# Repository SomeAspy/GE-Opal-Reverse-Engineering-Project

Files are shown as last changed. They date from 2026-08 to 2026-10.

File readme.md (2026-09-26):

# GE-Opal-Reverse-Engineering-Project

This repository documents all my attempts to make the GE Opal 2 not kill itself
(More specifically, the *GE Profile:tm: Opal:tm: 2.0 Ultra Nugget Ice Maker )

Important context to a lot of frustration here: This is a $500 dollar ice machine. It has a lifespan of 6 months to 1 year

## Consider sponsoring

I have quite literally dumped hundreds of dollars into this project.
Some of the costs are prototyping modules, connectors, electronics components, and OEM parts for the machine.

**Money spent on this project so far: $768.73**

_this does not factor in my time spent on the project_

(500 dollar ice machine by the way)

## Directory

- [`reverse-engineering-efforts/`](./reverse-engineering-efforts) - Generally contains specifics about the hardware of the Opal 2
  - [`i2c.md`](./reverse-engineering-efforts/i2c.md) - Details of the I2C implementation in the original machine
  - [`pipes.d2`](./reverse-engineering-efforts/pipes.d2) - D2 file for generating `pipes.svg`
  - [`pipes.svg`](./reverse-engineering-efforts/pipes.svg) - How the Opal 2 is plumbed
- [`physical-repairs/`](./physical-repairs) - Details of specific repair efforts
  - [`gearboxRepair.md`](physical-repairs/gearboxRepair.md) - Details about the gearbox and the procedures and parts to fix it
  - [`squeakFromShaft.md`](physical-repairs/squeakFromShaft.md) - Details about a repair attempting to stop the squeaking shaft
- [`hardware/`](./hardware) - PCB related stuff
  - [`RoughSketch-ArduinoNanoESP32`](./hardware/RoughSketch-ArduinoNanoESP32) - Details the rough prototype build with modular components before the PCB fabrication
    - [`prototype-parts.md`](./hardware/RoughSketch-ArduinoNanoESP32/prototype-parts.md) - A list of the exact modules I used for prototyping
    - [`Schematic.pdf`](./hardware/RoughSketch-ArduinoNanoESP32/Schematic.pdf) - A human readable version of the schematic, made by printing to PDF from KiCAD
- [`attribution.md`](./attribution.md) - Links and references used for files
- [`todo.md`](./todo.md) - List of further research needed

## To Do

(in no specific order)

- [ ] Finish connectors.md with colors and diagrams
- [ ] Design PCB
- [ ] Reverse engineer I2C bus of other front panel [(Need parts)](./todo.md)
- [ ] Design full independent schematic
- [ ] Reverse engineer GE implementation of the RGB light [(Need parts)](./todo.md)

## Default button mappings

A few new button actions are defined, and a few changed from the original machine behavior

- **Power**: Toggles Power
  - **When held**: Triggers a hard reset of the Arduino. _I hope you know what you're doing_
- **Light**: Toggles Light
- **Clean**: Toggles cleaning mode. In my implementation, there is no timer or anything. It simply forces the pump to run until it is pressed again.

## The Prototype

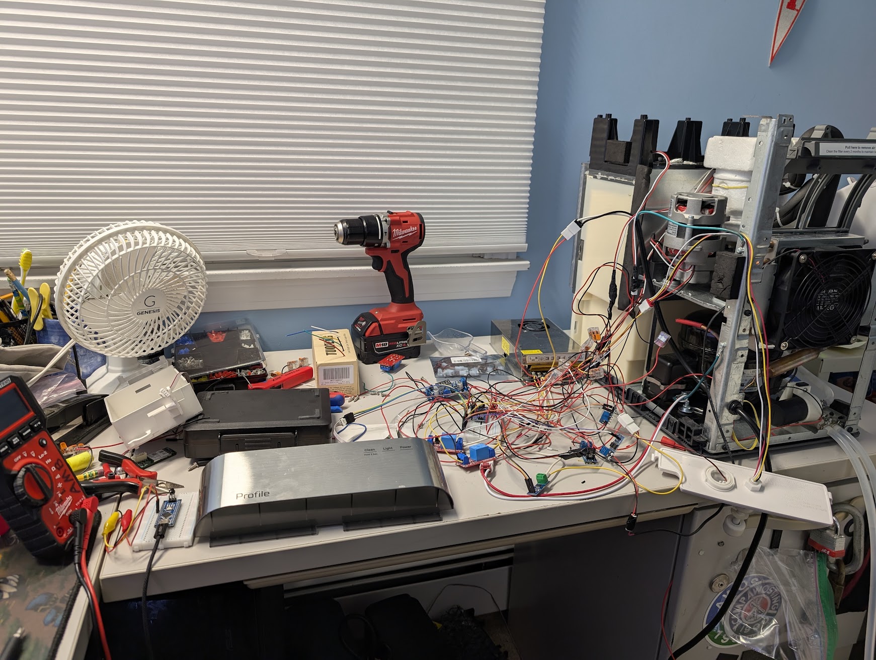
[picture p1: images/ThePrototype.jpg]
Mess of wires and stuff coming from the ice machine


> [!WARNING]  
> Schematics and code are not final!

### LLM Policy and usage in this project:

I hate LLMs, and "AI" crap. Therefore, I decided to very clearly define how they were used in this project.

- I did **NOT** copy-paste code or otherwise use LLM generated material in this project's code.
- An LLM was used to help me understand how to use KiCAD because I have never used it before.
- An LLM was used to sanity check ([rubber ducky](https://en.wikipedia.org/wiki/Rubber_duck_debugging)) to avoid killing the machine.
- An LLM was used to help me understand the basics of I2C and reverse engineer the communication the Opal uses.
  - **I** implemented the I2C communications in the firmware.

Do **NOT** submit LLM generated issues, PRs, or use this repo in training data.

You **MAY** submit an **issue** that you made with the assistance of an LLM, but you must **paraphrase and understand** the content in your own words.

### My blog post on this

[A Scathing Review of the GE Opal 2 Nugget Ice Maker](https://blog.aspy.dev/a-scathing-review-of-the-ge-opal-2-nugget-ice-maker/)

# Background

I've tried putting lubrication on the auger ([`squeakFromShaft.md`](./physical-repairs/squeakFromShaft.md)) but it did not resolve the squeaking issue
I've decided I am going to replace the PCB with an arduino to implement a proper defrost cycle.

## Notice

As I was writing this, Reddit decided to delete the 2 year old post I was using as a reference.
Some of the more important images are available in [`images`](./images).

<https://web.archive.org/web/20250804095737/https://www.reddit.com/r/IceChewersAnonymous/comments/1hxlbkg/fixing_the_opal_20/>

## The Problem

The GE Opal ice maker has well-known issues where it will start to fail after about a year of use, and in some cases, prior.
The machine is incredibly high maintenance, [with GE recommending running bleach through the machine](https://products.geappliances.com/appliance/gea-support-search-content?contentId=000060634) ([archive.org capture](https://web.archive.org/web/20260716162758/https://products.geappliances.com/appliance/gea-support-search-content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))

There is even (as of writing) [an ongoing class action](https://classlawdc.com/2026/01/21/ge-profile-opalnugget-ice-maker-series-1-0-and-2-0-defective-product-investigation/)

These machines do not fail gracefully, often making screeching and whining noises due to the internal parts getting frozen and locked up. This commonly involves the destruction of the gearbox, auger, and/or bearings.

Browsing Reddit reveals many owners have constant issues with these machines, with one redditor even claiming to go through 4 machines in 2 years. Despite its flaws, this machine is well liked by r/IceChewersAnonymous, though they also agree that it has significant longevity issues. [A quick search shows the love/hate the community has for it.](https://www.reddit.com/r/IceChewersAnonymous/search/?q=opal+2)

More importantly, several members of the community have taken attempts to repair the machine pretty far.

- https://www.reddit.com/r/IceChewersAnonymous/comments/1ophadu/opal_20_repair_update/
- https://www.reddit.com/r/IceChewersAnonymous/comments/1hxlbkg/fixing_the_opal_20/
- https://www.reddit.com/r/IceChewersAnonymous/comments/159ts6e/ge_opal_20_add_water_fix/

# Piping

Piping

# Nominal voltages recorded from the opal 2 ice maker during operation

_I am aware that JST XHB is not a real standard. However, this is the bastardized cloned modification China has made. it is a JST XH connector with a locking tab. You will not find them on Amazon, or Digikey. I found mine [on Aliexpress](https://www.aliexpress.us/item/3256812673164043.html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)._

_Same applies to JST HY. With some help from ~~the Arduino Community~~[^1] a specific member of the Arduino community and JLCPCB, I was able to find what appears to be a matching connector.
~~[LCSC #C42451574](https://www.lcsc.com/product-detail/C42451574.html)~~_) (Not quite it yet)

| PCB Label | Part | Connector Type & Color | Voltage |
| --- | --- | --- | --- |
| UV | UV Light | JST XHB 2-pin connector (Blue) | 12V DC |
| compressor | Compressor | JST VHR 3-pin connector (Red) | 120V AC |
| motor | Auger Motor | JST VHR 3-pin connector (White)  | 120V AC |
| WP | Pump | JST XHB 2-pin connector (Purple) | 12V DC |
| FAN1 | Fan | JST XHB 2-pin connector (Gray) | 12V DC |
| WIFI | WiFi Board | JST HY 5-pin connector (White) | 3.3V + 5V DC |
| IM1101 | Front Panel | JST XHB 4-pin connector (Black)  | 5V + I2C |
| LED11 & LED12 | Ice Box LED(s?) | JST XHB 2-pin connector (White)  | 12V DC |
| SW | Ice box presence switch | JST XHB 2-pin connector (Red) | 5V DC |
| CON5 | Internal Tank Floats | JST HY 4-pin connector (Red) | 5V DC |
| TX | IR LED For Capacity | JST XHB 2-pin connector (Yellow) | 5V DC |
| RX | IR Receiver | JST XHB 2-pin connector (Green)  | 5V DC |
| AC | AC Input | JST VHR 3-pin connector (Black)  | 120V AC |
| IMN1001 | ??? | JST HY 7-pin connector (White) | ??? |
| CON6 | ??? | JST HY 6-pin connector (White) | 5V + ??? |
| Clean | ??? | JST XHB 2-pin connector (Cyan) | ??? |
| RGB | ??? | JST XHB 3-pin connector (White)  | 5V + ??? |
| 1033 | ??? | JST XHB 3-pin connector (Black)  | 5V + ??? |
| CON3 | ??? | JST XHB 3-pin connector (Red) | ??? |
| ??? | ??? | JST HY 5-pin connector (Black) | 5V + ??? |

- I2C protocols documented in [`i2c.md`](./reverse-engineering-efforts/i2c.md)

- Internal Tank Floats (4 wires, 2 floats)
  - Black & Red: Lower float (float low = closed circuit)
  - Yellow & White: Upper float (float high = closed circuit)

## FAQ

### Why an ESP32 based board instead of a standard 8-bit Atmel board?

The idea was to keep it simple, but I started running into issues once I got the HLW8032.
Unlike the ACS712 which uses analog to communicate with the Arduino, the HLW8032 uses serial.
The original board I was planning to use and prototyping with, the Arduino Nano, only has 1 serial bus. That being the main USB port. This would mean you cannot program the controller while the HLW8032 is connected. I did not like that.
Furthermore, all the Arduino libraries for reading from the HLW8032 assume 32-bit math, which breaks down on the Arduino Nano.

### What about WiFi? The app?

I decided to completely ignore this, as a WiFi connected ice machine is just stupid.
Maybe I will add it some day, but there are 2 ways to go about it. The OEM WiFi daughterboard communicates to the motherboard via serial. You can either use that and just pretend to be the OEM motherboard, or you could completely rebuild/reverse-engineer the connection to the SmartHQ app, which... yikes...

### Can I buy a board?

Not yet.

## Special Thanks

- My Grandfather, a retired Raytheon engineer for verifying my 120v components
- The Adafruit Discord team for being wholly interested in my project [Join their Discord](http://adafru.it/discord)
- Gan, from the JLCPCB team for helping me hunt down the weird connectors GE used
- Carlos, from the Arduino support team for verifying my intuition that the Nano ESP can drive several hundred mA
- bitSmith, a volunteer moderator of the official Discord Arduino community for banning me and my younger brother for absolutely no reason - leading to me finding the Adafruit Discord

## Legal stuff

- The designs and software within are provided as-is without warranty of any kind, express or implied
- GE, GE Profile, Opal, Adafruit, ESP32, and Arduino trademarks are property of their respective owners. In no way do they endorse the contents contained within.
- This project utilizes mains voltage. Use at your own risk. You have been warned.
- This project uses 2 licenses, GPLv3 for the code and Creative Commons Attribution-NonCommercial 4.0 International for the hardware designs. Exemptions may be requested by contacting me.

[^1]: A massive shoutout to the "Official" Arduino Discord volunteer moderation team (_**bitSmith**_), who permanently banned me (and my younger brother, despite having no involvement except association) from their Discord server and belittled me and talked to me in a condescending way when I was migrating to ESP32. If you are reading this, yes, the Arduino Nano ESP32 CAN power 2 relays on the 3.3v line because it has a regulator that can easily handle 1A. To quote bitSmith, it will not work "because of physics. and logic." I later emailed Arduino directly asking for clarification, and yes, it can handle 1A.

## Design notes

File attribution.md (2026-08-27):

# Attribution

All images, Diagrams, Schematics _**made by me**_ fall [under this project's license](./license.txt)
Items not by me property of their respective owners.

## IMAGES

- [images/shreddedGearbox.webp](./images/shreddedGearbox.webp) - [u/Budget_Rutabaga3739](https://www.reddit.com/user/Budget_Rutabaga3739/) - <https://www.reddit.com/r/IceChewersAnonymous/comments/1hxlbkg/fixing_the_opal_20/>
- [images/bearingSizes.webp](./images/bearingSizes.webp) - [u/Budget_Rutabaga3739](https://www.reddit.com/user/Budget_Rutabaga3739/) - <https://www.reddit.com/r/IceChewersAnonymous/comments/1hxlbkg/fixing_the_opal_20/>
- [images/greasedBushing.jpg](./images/greasedBushing.jpg) - Photo by me
- [images/greasedShaftTop.jpg](./images/greasedShaftTop.jpg) - Photo by me
- [images/greaseSpread.jpg](./images/greaseSpread.jpg) - Photo by me
- [images/scratchedBushing.png](./images/scratchedBushing.png) - Photo by me

## DIAGRAMS

- [reverse-engineering-efforts/pipes.svg](./reverse-engineering-efforts/pipes.svg) - generated from [reverse-engineering-efforts/pipes.d2](./reverse-engineering-efforts/pipes.d2), made by me

## SCHEMATICS

- [custom-pcb/prototype/SchematicExport.pdf](./custom-pcb/prototype/SchematicExport.pdf) - generated from [custom-pcb/prototype/kicadSchematic](./custom-pcb/prototype/kicadSchematic)

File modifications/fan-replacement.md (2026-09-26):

# Fan replacement

The original fan on the Opal 2 is cheap trash.
I replaced mine with a [Noctua NF-P12 Redux](https://www.amazon.com/dp/B07CG2PGY6)
Any standard 120mm computer fan (PWM or not) should work.

Since the machine doesn't have PWM (and doesn't need it, since we are cooling a compressor anyway) only 2 of the 4 connections on this fan are used.

Black is 12V negative, and Yellow is 12V Positive.

Black -> Black

Yellow -> Red

Simply splice those into the original fan connector.

Ensure the fan is blowing _away_ from the machine, so the arrow on the fan should be pointing away from the machine.

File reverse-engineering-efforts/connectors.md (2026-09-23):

# Connectors

## How to use this information

Assume you are looking down the connector from above, with the locking tab on the left.

Wires are listed in the order they appear.

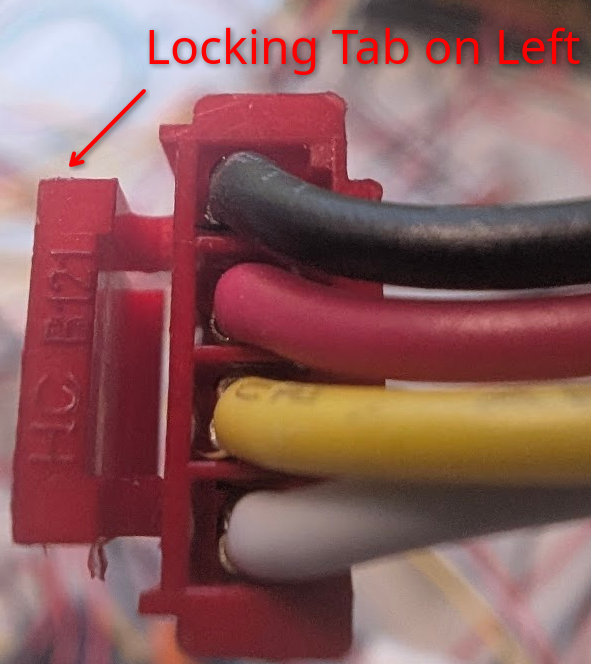
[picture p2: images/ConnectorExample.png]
Red connector with locking tab on left


This would be listed like

- Black
- Red
- Yellow
- White

> [!WARNING]  
> **CHECK EVERY WIRE. GE IS NOT CONSISTENT IN WIRE COLOR CODING.**
>
> You are probably better off only referring to connectors by the alignment of the wires in reference to the locking tab rather than color
> _For example, the IR Receiver and IR Blaster both have Red and White wires, but the polarity is reversed on one._

### AC Header (Black)

JST VHR 3-pin connector (No center pin)

- LINE (Black)
- N/A
- NEUTRAL (White)

### Compressor Header (Red)

JST VHR 3-pin connector (No center pin)

- NEUTRAL (White)
- N/A
- LINE (Red)

### Motor Header (White)

JST VHR 3-pin connector (No center pin)

- NEUTRAL (Red)
- N/A
- LINE (Black)

### UV Header (Blue)

JST XHB 2-pin connector

- 12V DC
- GND

### IR Receiver (Green)

JST XHB 2-pin connector

- GND (Red)
- 5V DC (White)

### IR Blaster (Yellow)

JST XHB 2-pin connector

- GND (White)
- 5V DC (Red)

### UV LED (Orange)

JST XHB 2-pin connector

- 12V DC (Red)
- GND (Black)

### Fan (Gray)

JST XHB 2-pin connector

- GND (Black)
- 12V DC (Red)

### Pump (Purple)

JST XHB 2-pin connector

- GND (Black)
- 12V DC (Red)

### Bin Switch (Red)

JST XHB 2-pin connector

(Being a switch, polarity isn't neccesarily relevant.)

- 5V DC (White)
- GND (Red)

## Water Level Floats (Red)

JST XHB 4-pin connector

(Being a switch, polarity isn't neccesarily relevant.)

When the LOWER FLOAT is LOW the circuit is CLOSED.
When the UPPER FLOAT is HIGH the circuit is CLOSED.

Ex:

tank empty = Upper Float OPEN, Lower Float CLOSED

tank full = Upper Float CLOSED, Lower Float OPEN

- Lower Float GND (Black)
- Lower Float 5V DC (Red)
- Upper Float ???? (Yellow)
- Upper Float ???? (White)

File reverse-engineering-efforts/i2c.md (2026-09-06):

# The front panel

The front panel appears to be communicating with the motherboard over I2C

Originally, I had a cooldown on communications to not hammer it with queries, but I found it does not care and will happily answer the arduino's queries hundreds of times a second.

## Device Addresses

| Address | Device |
| :-----: | :---: |
| `0x60`  | Front Panel |

## Button Codes (Received from `0x60`)

|  Hex | Action |
| :----: | :---: |
| `0x00` | Button Released |
| `0x01` | Clean Pressed |
| `0x02` | Light Pressed |
| `0x03` | Power Pressed |
| `0x04` | Power Held |
| `0x05` | Light Held |
| `0x06` | Clean Held |
| `0x07` | Power + Clean Pressed |
| `0x08` | Clean + Light Pressed |
| `0x09` | Light + Power Pressed |

Note that holding buttons fires both the initial button pressed code and then the Held code after 3 seconds of holding

For example, pressing and holding power:

1. Power button detects interaction
2. `0x03` fired
3. Power button is held for 3 seconds
4. `0x04` fired
5. Power button released
6. `0x00` fired

I popped the microcontroller on my original front panel that also had `Descale` and `Sanitize` LEDs. The replacement board I got does not have these LEDs, so I am unable to reverse engineer the codes as of now.

## Light Codes (Sent to `0x60`)

|  Hex | Action |
| :----: | :---: |
| `0x00` | All Off |
| `0x01` | Clean |
| `0x02` | Light |
| `0x04` | Power |
| `0x08` |  Add Water  |
| `0x10` | Making Ice  |
| `0x20` |  Cleaning |
| `0x40` | Defrosting  |
| `0x80` | WiFi Symbol |

Light codes are sent as bitmask. If you want to turn on multiple LEDs then you add the bits.
For example:

`0x01 | 0x80` = Clean + WiFi Symbol

`0x02 | 0x04 | 0x20` = Light + Power + Cleaning

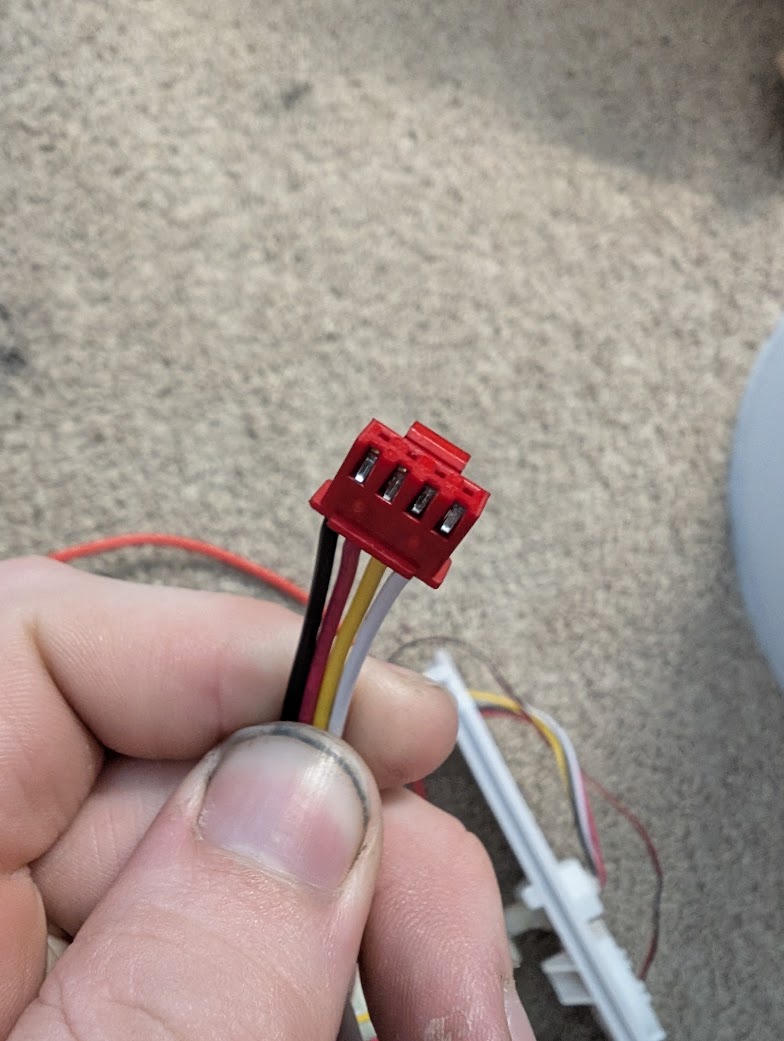
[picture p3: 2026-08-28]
images/floatConnector.jpg

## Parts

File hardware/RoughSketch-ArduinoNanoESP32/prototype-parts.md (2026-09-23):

## Ammeter

HLW8032 UART Communication Module AC Voltage Current Sensor 4800bps Serial Energy Monitoring Device with Isolation for Design for Industrial Power Measurement Data Collection
<https://www.amazon.com/dp/B0H94DFTMJ>

## Arduino Nano ESP32

Arduino Nano ESP32 with Headers [ABX00083] - ESP32-S3, USB-C, Wi-Fi, Bluetooth, HID Support, MicroPython Compatible for IoT & Embedded Projects
<https://www.amazon.com/dp/B0C947BHK5>

## Relays

4pcs DC 5V Relay Module - 1 Channel Relay Switch Board with Optocoupler Isolation, High or Low Level Trigger
<https://www.amazon.com/dp/B095YD3732>

## Shift Registers

5 Pack 4-Channel IIC I2C Level Converter Module Bi-Directional Logic Level Shifter 5V to 3.3V for Arduino Raspberry Pi ESP8266 ESP32 Sensors Presoldered Compact Adapter Board
<https://www.amazon.com/dp/B0F9NCV286>

## Buck Converter for 5V line off of 12V line

5Pcs LM2596S DC-DC LM2596 with LED Display Voltmeter Buck Converter Step-Down Regulator 4.0-40V to 1.25-37V DC 36V to 24V to 12V to 5V Power Supply Module Compatible with Car Motor Buck
<https://www.amazon.com/dp/B089KBS5XR>

## Mosfets

6Pcs MOSFET Switch Drive Module DC 5V-36V 15A (Max 30A) 400W
<https://www.amazon.com/dp/B0D9VWWLCB>

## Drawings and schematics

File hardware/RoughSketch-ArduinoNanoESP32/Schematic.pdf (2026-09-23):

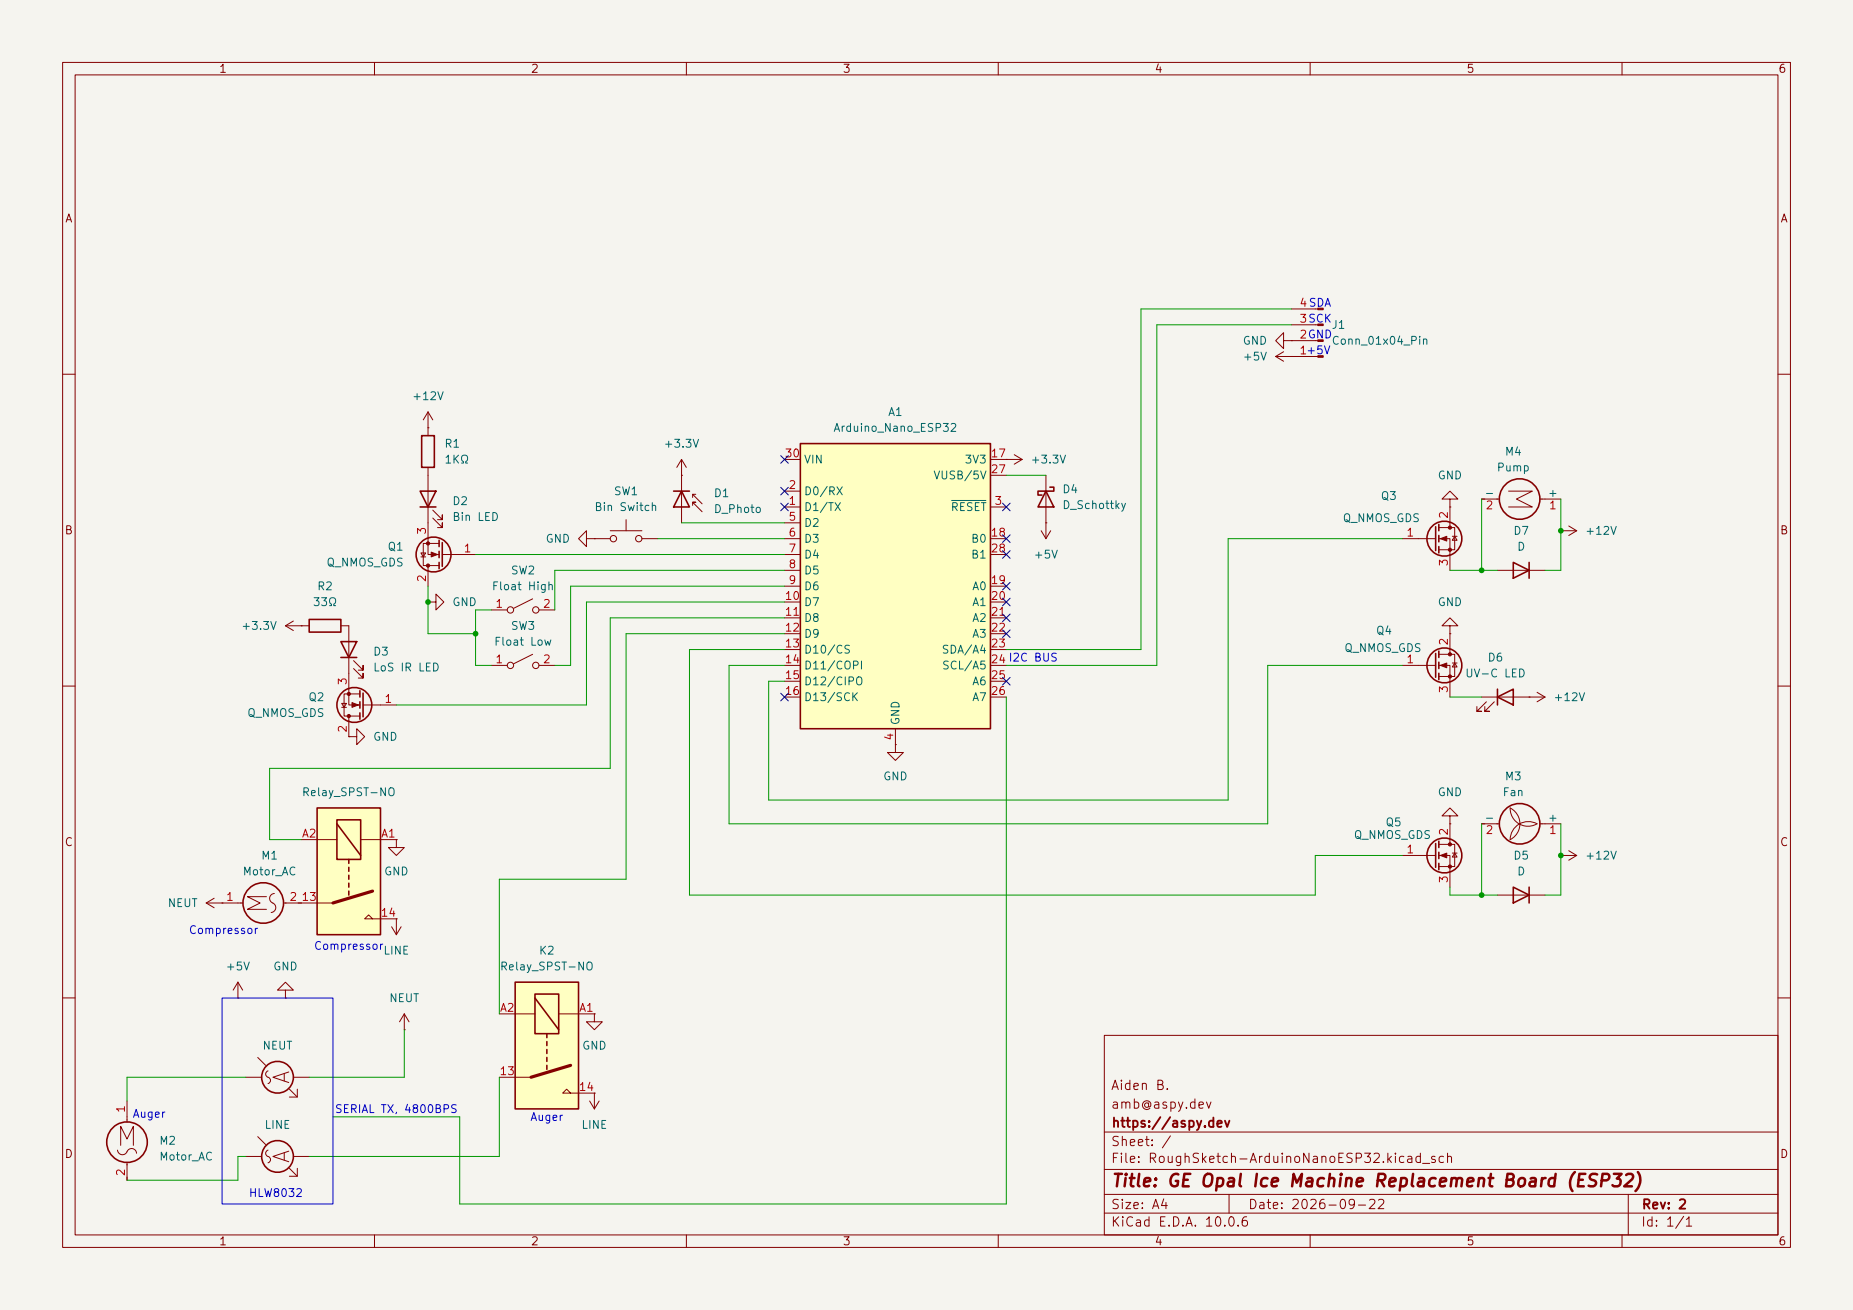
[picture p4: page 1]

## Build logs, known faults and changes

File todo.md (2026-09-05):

# Parts to research

## Donations welcome! If you would like to help in research of this machine heres what you can do

- Sponsor the project <https://github.com/sponsors/SomeAspy>
- Send me parts I don't have (email me at amb@aspy.dev to help)
- Make PRs or issues for the repo with your own findings

## Front panel

My original GE front panel board had a total of 7 LEDs. (an extra Descale and Sanitize LED)
Unfortunately, before I began the reverse engineering project, that board died.
I have no way of knowing how to toggle these LEDs without a working board to test.
I was unable to find a replacement for this version of the board with 7 LEDs, and the current documentation only covers the 5 LED version

## RGB

The original GE motherboard has 2 headers for what appears to be RGB, and the [GE Opal Mini Pro](https://www.geappliances.com/appliance/GE-Profile-Opal-Mini-Pro-Nugget-Ice-Maker-with-Side-Tank-P4NM25QZSS) brags about an RGB LED in the features.
This makes me think the motherboards are mostly unchanged between revisions. I was unable to find parts for this on Ebay.
Additionally, research points to some other models of the ice maker having RGB lights for [status indication](https://products.geappliances.com/appliance/gea-support-search-content?contentId=39617)

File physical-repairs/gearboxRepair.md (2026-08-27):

# Repairing the gearbox of the Opal 2

While gearboxes can be pretty easily sourced on eBay, this goes over working on the gearbox you have.

## Tutorial for dismantling the machine

<https://www.youtube.com/watch?v=qTffBY9GRwQ>

## Parts

- 1x 6002zz bearing ([SKF](https://www.skf.com/sg/products/rolling-bearings/ball-bearings/deep-groove-ball-bearings/productid-6002-2Z))
- 2x 696zz bearings ([SKF](https://www.skf.com/group/products/rolling-bearings/ball-bearings/deep-groove-ball-bearings/productid-619%2F6-2Z))
- 4x 695zz bearings ([SKF](https://www.skf.com/group/products/rolling-bearings/ball-bearings/deep-groove-ball-bearings/productid-619%2F5-2Z))
- Food-safe low-temperature synthetic NGLI 2 grease ([Super Lube 21030 Synthetic Multi-Purpose Grease](https://www.amazon.com/dp/B000XBH9HI) happens to fit these requirements)

> [!CAUTION]
> You cannot use any type of grease in the gearbox. **It must be food safe (NSF H1)**
> Additonally, it must be stable in cold environments (Under -40F), and must be plastic and rubber safe.
> It must also be NLGI 2 viscosity

## Bearings

The bearings in the GE Opal 2 are known to catastrophically fail, taking the machine with them.
This can be mitigated (to some extent) by replacing the bearings with high quality ones.

If you have the gearbox open, you might as well replace them all.

[The original poster](https://www.reddit.com/r/IceChewersAnonymous/comments/1hxlbkg/fixing_the_opal_20/) used UXCell brand bearings from amazon, but they failed after 10 months.

It is reccomended you use high quality bearings.
Reputable companies include [SKF](https://www.skf.com/us/products/bearings), [NSK](https://www.nsk.com/am-en/), [TIMKEN](https://www.timken.com/engineered-bearing-solutions/), [NTN](https://bearingfinder.ntnamericas.com/), and [FAG](https://www.schaeffler.us/us/products-and-solutions/industrial/)

GE Opal Gearbox bearing sizes

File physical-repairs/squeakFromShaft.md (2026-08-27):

# Attempted fix for the auger shaft sqeaking

After my machine started making noise, I determined it seemed to be coming from where the shaft of the auger meets the housing.

The housing at the top of the auger appears to have a plastic bushing, which in my case seemed in bad shape
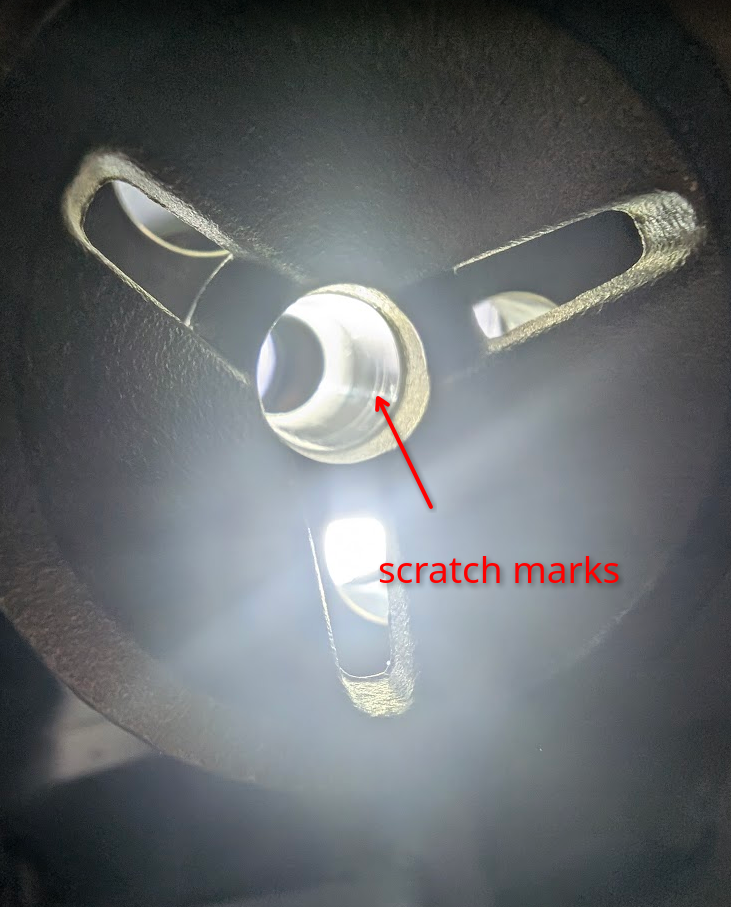
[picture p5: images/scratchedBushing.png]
scratched bushing


I attempted to remove the plastic bushing, to attempt replacing it with a proper bearing but was unable to get it out.

I ended up just applying [Super Lube 21030 Synthetic Multi-Purpose Grease](https://www.amazon.com/dp/B000XBH9HI) to the top and the bushing at the bottom of the shaft.

Before applying new grease, make sure you remove all the old grease first (if there is any)
This is also a good time to inspect the auger and housing for damage/scale. In my case scale usually looked like a white powder that could be easily removed with a cloth.

You should spread the grease, so you dont have a big blob that will just be scraped off when its inserted.
You can do it with your fingers or a small tool.

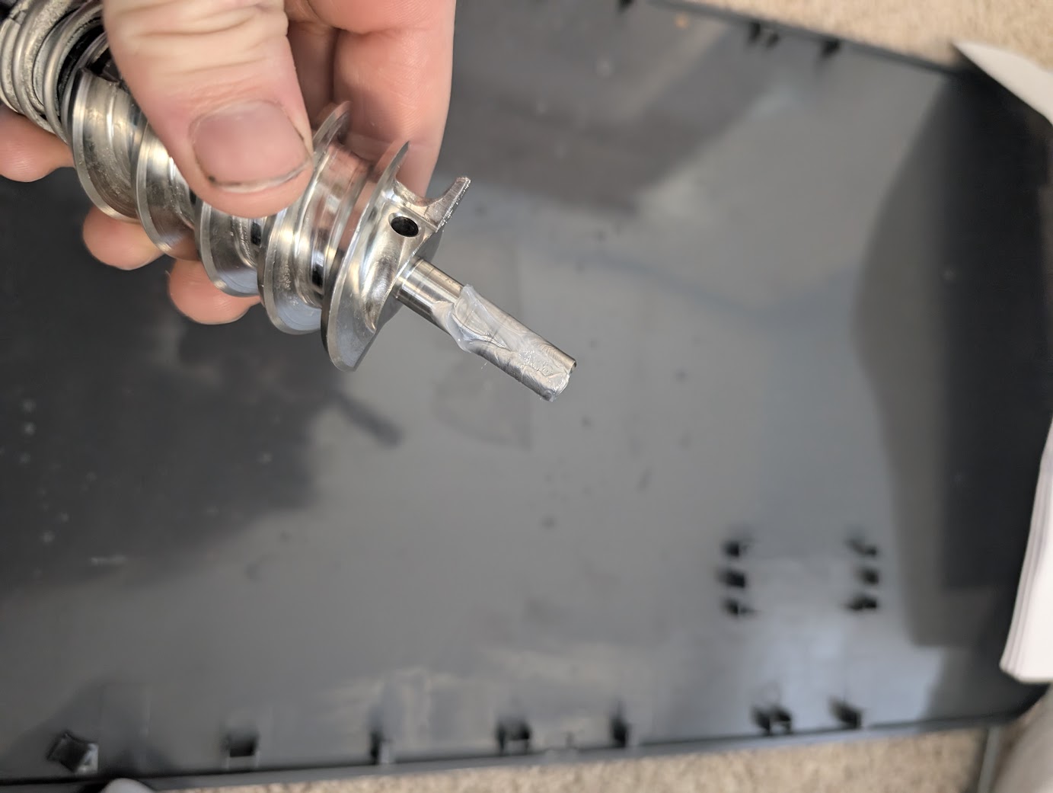
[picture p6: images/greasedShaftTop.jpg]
greased shaft top

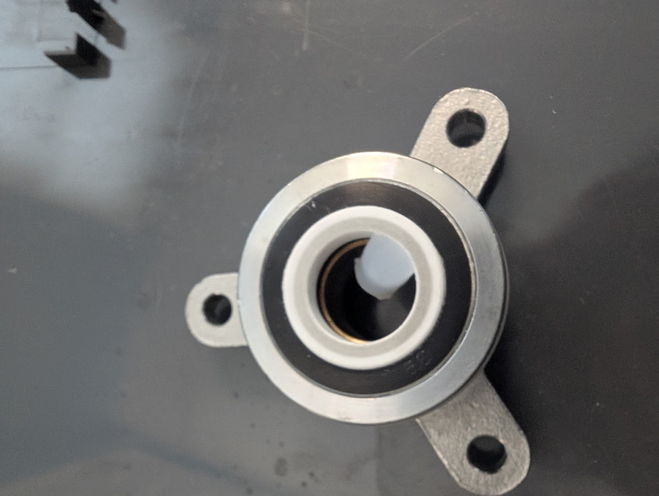
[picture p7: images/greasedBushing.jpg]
greased bushing

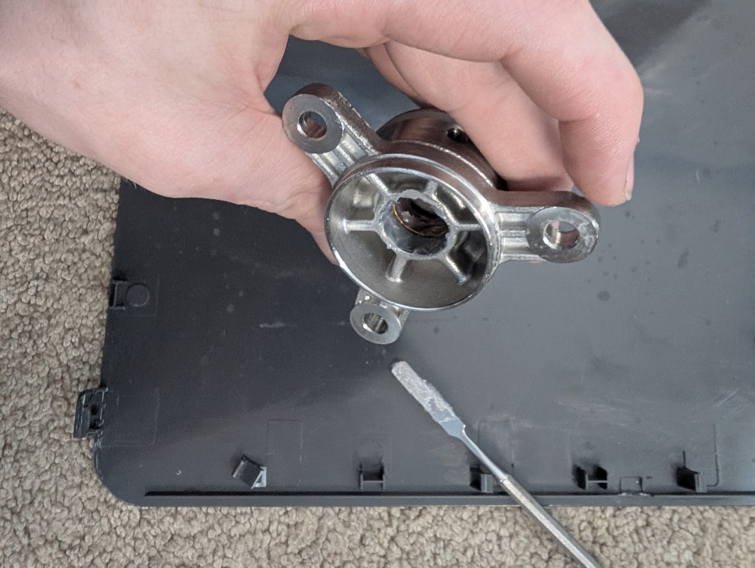
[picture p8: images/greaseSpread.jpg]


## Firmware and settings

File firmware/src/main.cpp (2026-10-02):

// Copyright (C) 2026 SomeAspy (Aiden B. amb@aspy.dev)
// SPDX-License-Identifier: GPL-3.0-only
// https://github.com/someaspy/GE-Opal-2-fixes

#include "WString.h"
#include "constants.h"
#include "hlw8032.h"
#include <Preferences.h>
#include <Wire.h>
#include <algorithm>
#include <hd44780.h>
#include <hd44780ioClass/hd44780_I2Cexp.h>

namespace {

// Front panel communication
uint8_t lastButtonPress = button::idle;

// Water management
bool pumping = false;
unsigned long pumpStartedTime = 0;

// Compressor management
// If the machine is off, assume its been off for a safe amount of time
unsigned long compressorStopTime = -compressor_cooldown;
unsigned long compressorStartTime = 0;
bool isCompressorRunning = false;

// Auger & defrost cycle management
bool defrostCycle = false;
unsigned long defrostCycleStartTime = 0;

// Bin management
unsigned long binCheck = 0;
unsigned long binLastFullAt = 0;
bool binFull = false;

// General state initialization
bool tankEmptyHalt = false;
bool isPowered = false;
bool isLightOn = false;
bool isCleaning = false;

// Initialized later by EEPROM
bool enableBinLed;

HLW8032 energyMonitor;

Preferences store;

// Give the energy monitor serial an acceptable name
HardwareSerial energySerial(1);
hd44780_I2Cexp lcd;
float maxPowerSeen = 0;
} // namespace

void setup() {
  store.begin("store", false);
  Serial.begin(115200);
  Wire.begin();
  energySerial.begin(4800, SERIAL_8N1, pin::energy_monitor, -1);

  // Grounded inputs need to be pulled up
  pinMode(pin::bin_switch, INPUT_PULLUP);
  pinMode(pin::tank_full, INPUT_PULLUP);
  pinMode(pin::tank_empty, INPUT_PULLUP);

  // Live inputs need to be pulled down
  pinMode(pin::ir_receiver, INPUT);

  // Outputs
  pinMode(pin::ir_blaster, OUTPUT);
  pinMode(pin::compressor, OUTPUT);
  pinMode(pin::auger, OUTPUT);
  pinMode(pin::fan, OUTPUT);
  pinMode(pin::uv_led, OUTPUT);
  pinMode(pin::pump, OUTPUT);
  pinMode(pin::bin_led, OUTPUT);

  if (!store.isKey("enableBinLed")) {
    store.putBool("enableBinLed", false);
  }
  enableBinLed = store.getBool("enableBinLed");
  lcd.begin(20, 4);
  lcd.backlight();
  lcd.setCursor(0, 2);
  lcd.print("Max: " + static_cast<String>(auger_wattage_draw_limit) + " Watts");
}

void loop() {
  // DIGITAL READS ARE INVERTED BECAUSE WE PULL UP!!!
  // Read values for the current cycle
  const bool isTankFull = !digitalRead(pin::tank_full);
  const bool isTankEmpty = !digitalRead(pin::tank_empty);
  const bool isBinInserted = !digitalRead(pin::bin_switch);

  while (energySerial.available()) {
    energyMonitor.processData(static_cast<uint8_t>(energySerial.read()));
  }
  Wire.requestFrom(front_panel_i2c_address, static_cast<uint8_t>(1));
  if (Wire.available()) {
    auto buttonCode = static_cast<uint8_t>(Wire.read());
    if (buttonCode != lastButtonPress) {
      switch (buttonCode) {
      case button::power:
        isPowered = !isPowered;
        tankEmptyHalt = false;
        break;
      case button::light:
        isLightOn = !isLightOn;
        store.putBool("enableBinLed", isLightOn);
        digitalWrite(pin::bin_led, isLightOn);
        break;
      case button::clean_held:
        isCleaning = true;
        break;
      case button::clean:
        isCleaning = false;
        break;
      case button::power_held:
        ESP.restart();
        break;
      default:;
      }
      lastButtonPress = buttonCode;
    }
    uint8_t currentLights = 0x0;
    if (isPowered) {
      currentLights |= led::power_button;
    }
    if (defrostCycle) {
      currentLights |= led::defrosting;
    }
    if (tankEmptyHalt) {
      currentLights |= led::add_water;
    }
    if (isLightOn) {
      currentLights |= led::light_button;
    }
    if (isCompressorRunning) {
      currentLights |= led::making_ice;
    }
    if (isCleaning) {
      currentLights |= led::cleaning | led::clean_button;
    }
    Wire.beginTransmission(front_panel_i2c_address);
    Wire.write(currentLights);
    Wire.endTransmission();
  }

  // When the machine should be stopped
  if (!isPowered || tankEmptyHalt || defrostCycle || binFull || isCleaning) {
    if (!isCleaning) {
      digitalWrite(pin::pump, false);
      digitalWrite(pin::uv_led, false);
    } else {
      digitalWrite(pin::pump, true);
      digitalWrite(pin::uv_led, true);
    }
    digitalWrite(pin::compressor, false);
    digitalWrite(pin::fan, false);
    digitalWrite(pin::auger, false);
    pumping = false;

    // Start compressor cooldown
    if (isCompressorRunning) {
      compressorStopTime = millis();
      isCompressorRunning = false;
    }

    // If the bin is open we can assume ice was removed
    if (!isBinInserted) {
      tankEmptyHalt = false;
      binFull = false;
      binCheck = 0;
    }
    // If the defrost cycle triggered the halt and is done, start the machine
    if (millis() - defrostCycleStartTime > defrost_cycle_length &&
        defrostCycle) {
      defrostCycle = false;
    }

    // If the bin being filled triggered the halt, clear once ice making
    // cooldown finishes
    if (millis() - binLastFullAt > bin_full_pause && binFull) {
      binFull = false;
    }
    return;
  }

  // IR Receiver needs a moment to register it's state
  digitalWrite(pin::ir_blaster, true);
  delay(10);
  // Pull up resistor on the IR
  const bool irReceiving = !digitalRead(pin::ir_receiver);
  digitalWrite(pin::ir_blaster, false);

  // If the pump doesn't move enough water into the tank, something is wrong
  if (pumping && (millis() - pumpStartedTime > pump_timeout)) {
    // We are probably out of water
    tankEmptyHalt = true;
    return;
  }

  // Don't stop pumping once the lower float rises, so we can fill it up to the
  // upper float to save pump spam
  if (isTankEmpty && !pumping) {
    digitalWrite(pin::uv_led, true);
    digitalWrite(pin::pump, true);

    pumping = true;
    pumpStartedTime = millis();
  }
  if (isTankFull && pumping) {
    // Stop the pump when the upper float triggers
    digitalWrite(pin::uv_led, false);
    digitalWrite(pin::pump, false);
    pumping = false;
  }

  // If IR LOS is broken, there is either ice actively falling or the bin is
  // full to rule out the first case, wait for the IR sensor to lose LOS for the
  // delay specified in bin_full_delay
  if (irReceiving) {
    binCheck = 0;
  }

  if (!irReceiving) {
    if (binCheck == 0) {
      binCheck = millis();
    } else if (millis() - binCheck > bin_full_delay) {
      binFull = true;
      binLastFullAt = millis();
      return;
    }
  }

  if (!isCompressorRunning) {
    // Don't abuse the compressor
    if (millis() - compressorStopTime < compressor_cooldown) {
      return;
    }
    // Wait if we are in the middle of checking the bin
    if (binCheck != 0) {
      return;
    }
    digitalWrite(pin::compressor, true);
    digitalWrite(pin::fan, true);
    digitalWrite(pin::auger, true);
    compressorStartTime = millis();
    isCompressorRunning = true;
  }

  // Stop the auger from blindly pushing harder when its jammed
  // Notably, the original machine has a light for defrost cycle, but I've never
  // seen it trigger, nor do I see a method of monitoring the motor on the
  // original motherboard
  const float activePower = energyMonitor.getActivePower();
  maxPowerSeen = max(activePower, maxPowerSeen);
  Serial.println(activePower);
  lcd.setCursor(0, 0); // Column 0, Row 0
  lcd.print(static_cast<String>(activePower) + " Watts");
  lcd.setCursor(0, 1); // Column 0, Row 1
  lcd.print("Max observed: " + static_cast<String>(maxPowerSeen));
  if (activePower >= auger_wattage_draw_limit &&
      millis() - compressorStartTime > auger_inrush_grace) {
    defrostCycle = true;
    defrostCycleStartTime = millis();
    return;
  }
}

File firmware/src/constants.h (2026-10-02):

// Copyright (C) 2026 SomeAspy (Aiden B. amb@aspy.dev)
// SPDX-License-Identifier: GPL-3.0-only
// https://github.com/someaspy/GE-Opal-2-fixes

// Pins
#include <Arduino.h>
#include <cstdint>

namespace pin {
constexpr uint8_t ir_receiver = 2;
constexpr uint8_t bin_switch = 3;
constexpr uint8_t bin_led = 4;
constexpr uint8_t tank_full = 5;
constexpr uint8_t tank_empty = 6;
constexpr uint8_t ir_blaster = 7;
constexpr uint8_t compressor = 8;
constexpr uint8_t auger = 9;
constexpr uint8_t fan = 10;
constexpr uint8_t uv_led = 11;
constexpr uint8_t pump = 12;
constexpr uint8_t energy_monitor = A7;
//  A4 and A5 are used for I2C

} // namespace pin

// Front Panel
constexpr uint8_t front_panel_i2c_address = 0x60;

// Bitmasks sent to Front panel
namespace led {
constexpr uint8_t clean_button = 0x01;
constexpr uint8_t light_button = 0x02;
constexpr uint8_t power_button = 0x04;
constexpr uint8_t add_water = 0x08;
constexpr uint8_t making_ice = 0x10;
constexpr uint8_t cleaning = 0x20;
constexpr uint8_t defrosting = 0x40;
constexpr uint8_t wifi = 0x80;
} // namespace led

// Bitmasks from the front panl
// button_idle_bitmask is also fired when a button is released
namespace button {
constexpr uint8_t idle = 0x00;
constexpr uint8_t clean = 0x01;
constexpr uint8_t light = 0x02;
constexpr uint8_t power = 0x03;
constexpr uint8_t power_held = 0x04;
constexpr uint8_t light_held = 0x05;
constexpr uint8_t clean_held = 0x06;
constexpr uint8_t clean_power = 0x07;
constexpr uint8_t clean_light = 0x08;
constexpr uint8_t power_light = 0x09;
} // namespace button

// Timing & variables

// 1m - Filter can drop flow a lot
constexpr unsigned long pump_timeout = 60000;
constexpr unsigned long compressor_cooldown = 300000; // 5m

// From testing the machine usually settles around 0.45A to 0.48A.
// 0.05 means the compressor is off. This probably means we have a calibration
// error.
// Note currentDrawLimit is ignored when the compressor first starts to
// accomodate inrush current. Tweak as needed.
constexpr float auger_wattage_draw_limit = 39.00;
constexpr unsigned long auger_inrush_grace = 15000; // 15s for inrush to settle
constexpr unsigned long defrost_cycle_length = 600000; // 10m

constexpr unsigned long bin_full_delay = 10000;
constexpr unsigned long bin_full_pause = 7200000;

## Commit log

2026-08-23 hooked up IR LED, reverse engineering details of front panel
    [rough-schematic-sketch.kicad_sch]
2026-08-23 Formatting i2c.md
2026-08-23 I think I've been committing to the internal firmware git repo
    [rough-schematic-sketch.kicad_sch]
2026-08-28 remove arduinoisms
2026-08-28 remove double arduino import
2026-09-02 add mosfet to bin LED
    [rough-schematic-sketch.kicad_sch]
2026-09-02 a few fixes, some of my wires were crossed
    [constants.h, main.cpp]
2026-09-02 update schematic
    [rough-schematic-sketch.kicad_sch]
2026-09-04 add a few things
    [rough-schematic-sketch.kicad_sch]
2026-09-04 switch line, not neutral
    [rough-schematic-sketch.kicad_sch]
2026-09-04 EEPROM safety railings
2026-09-05 remove buzzer, add needed components
    [rough-schematic-sketch.kicad_sch]
2026-09-23 Migration from Atmel to ESP32
    [.kicad_sch.kicad_sch, RoughSketch-ArduinoNanoESP32.kicad_pcb, RoughSketch-ArduinoNanoESP32.kicad_sch]
2026-09-24 Working prototype. No auger monitoring as I still need to calibrate it.
    remove hold
2026-11-08 handful of updates to code: - reduce pump timeout, my wire wasn't making proper contact consistently - remove the auger inrush grace (at some point I had confused the compressor inrush with auger?) -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
